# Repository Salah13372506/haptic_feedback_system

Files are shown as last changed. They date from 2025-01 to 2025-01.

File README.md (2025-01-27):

# Système de Retour Haptique avec Vision par Ordinateur

## Description du Projet

Projet réalisé dans le cadre du Master Systems for Rehabilitation (MSR) - Sorbonne Université.

Ce système d'assistance innovant a été conçu pour aider les personnes non-voyantes dans leur déplacement quotidien. Il combine la vision par ordinateur et le retour haptique pour détecter les obstacles et communiquer leur position à l'utilisateur via des vibrations. Développé initialement comme un système d'évitement d'obstacles, le projet a le potentiel d'évoluer vers une solution complète de navigation assistée.
Le système utilise une caméra de profondeur OAK-D pour détecter les obstacles et transmet l'information via des moteurs vibrants positionnés de manière ergonomique, permettant à l'utilisateur de percevoir intuitivement la direction des obstacles et de choisir un chemin sûr.
Ce projet s'inscrit dans une démarche d'innovation technologique au service de l'autonomie des personnes en situation de handicap visuel.






## Table des Matières

1. [Vue d'ensemble](#vue-densemble)
2. [Installation](#installation)
3. [Configuration de l'Espace de Travail](#configuration-de-lespace-de-travail)
4. [Nœuds ROS2](#nœuds-ros2)
5. [Partie Électronique](#partie-électronique)
6. [Partie Mécanique](#partie-mécanique)
7. [Documentation Utilisateur](#documentation-utilisateur)

## Vue d'ensemble

Ce projet implémente un système de détection d'obstacles et de retour haptique guidé par vision par ordinateur. Il utilise ROS2, une caméra de profondeur OAK-D, et des moteurs vibrants LRA (Linear Resonant Actuator) contrôlés par une carte Arduino MKR WiFi 1010.

## Installation

### Prérequis Système
- Ubuntu 22.04 LTS
- Python 3.10 ou supérieur
- Git
- VS Code avec PlatformIO

### ROS2 Humble
```bash
wget -c https://raw.githubusercontent.com/ros/rosdistro/master/ros.key && sudo apt-key add ros.key && sudo sh -c 'echo "deb [arch=amd64] http://packages.ros.org/ros2/ubuntu jammy main" > /etc/apt/sources.list.d/ros2.list' && sudo apt update && sudo apt install ros-humble-desktop-full
```

### Configuration Caméra OAK-D

1. Documentation officielle :
   - [Documentation Luxonis OAK-D](https://docs.luxonis.com/projects/api/en/latest/)
   - [Exemples DepthAI](https://github.com/luxonis/depthai-python/tree/main/examples)

2. Installation des dépendances :
   ```bash
   # Installation des dépendances système DepthAI
   sudo wget -qO- https://docs.luxonis.com/install_dependencies.sh | bash

   # Installation de la bibliothèque Python DepthAI
   python3 -m pip install depthai

   # Installation des dépendances ROS2
   sudo apt install ros-humble-depthai-ros
   ```

3. Test de l'installation :
   ```bash
   # Cloner les exemples
   git clone https://github.com/luxonis/depthai-python.git
   cd depthai-python/examples
   
   # Installer les dépendances Python
   python3 install_requirements.py
   
   # Tester la caméra
   python3 ColorCamera/rgb_preview.py
   ```

4. Vérification des règles udev :
   ```bash
   # Vérifier que la caméra est détectée
   lsusb | grep MyriadX
   
   # Si nécessaire, recharger les règles udev
   sudo udevadm control --reload-rules
   sudo udevadm trigger
   ```

### Configuration Arduino et PlatformIO (À lancer avant ROS2)

1. Installation de l'environnement de développement :
   ```bash
   # Installation de VS Code
   sudo apt update
   sudo apt install software-properties-common apt-transport-https wget
   wget -q https://packages.microsoft.com/keys/microsoft.asc -O- | sudo apt-key add -
   sudo add-apt-repository "deb [arch=amd64] https://packages.microsoft.com/repos/vscode stable main"
   sudo apt update
   sudo apt install code
   ```

2. Configuration de PlatformIO :
   - Ouvrir VS Code
   - Aller dans Extensions (Ctrl+Shift+X)
   - Rechercher "PlatformIO IDE"
   - Installer l'extension
   - Redémarrer VS Code

3. Structure du projet Arduino :
   ```
   haptic-arduino/
   ├── platformio.ini
   ├── src/
   │   └── main.cpp              # Code principal Arduino
   ├── lib/
   │   ├── Haptic_DRV2605/      # Bibliothèque des moteurs
   │   └── README.md
   └── include/
       └── README.md
   ```

4. Configuration détaillée dans `platformio.ini` :
   ```ini
   [env:mkrwifi1010]
   platform = atmelsam
   board = mkrwifi1010
   framework = arduino
   
   ; Configuration moniteur série
   monitor_speed = 115200
   monitor_flags = 
       --parity
       N
       --encoding
       UTF-8
   
   ; Dépendances externes
   lib_deps =
       arduino-libraries/WiFiNINA @ ^1.8.14
       bblanchon/ArduinoJson @ ^6.21.3
       Wire
       adafruit/Adafruit DRV2605 Library @ ^1.1.2
   
   ; Options de build
   build_flags =
       -D DEBUG_MODE
       -D WIFI_SSID=\"HapticArduino\"
       -D WIFI_PASS=\"haptic123\"
   
   ; Configuration mémoire
   board_build.f_cpu = 48000000L
   upload_speed = 115200
   ```

5. Compilation et téléversement :
   ```bash
   # Dans le dossier du projet Arduino
   pio run -t upload
   ```

6. Vérification du fonctionnement :
   ```bash
   # Ouvrir le moniteur série
   pio device monitor
   ```
   - Vérifier que l'Arduino crée bien le point d'accès WiFi
   - Confirmer l'initialisation des moteurs
   - Noter l'adresse IP (par défaut 192.168.4.1)

## Nœuds ROS2

### Objectifs des Nœuds

#### 1. Nœud Processeur de Profondeur (processor_node.py)
Ce nœud reçoit les données brutes de la caméra de profondeur et les traite pour identifier les obstacles.
Il normalise les données de profondeur et publie une image traitée où les obstacles proches sont plus sombres.

#### 2. Nœud de Projection 2D (2d.py)
Ce nœud transforme l'image de profondeur traitée en une projection 2D avec détection d'obstacles.
Il analyse la position des obstacles et détermine de quel côté l'utilisateur doit se diriger.

#### 3. Nœud de Publication Haptique (haptic_publisher.py)
Ce nœud gère l'activation des différents moteurs haptiques selon les commandes reçues.
Il maintient deux groupes de moteurs (gauche et droite) et coordonne leurs activations.

#### 4. Nœud Bridge WiFi (wifi_bridge.py)
Ce nœud établit la communication WiFi entre ROS2 et l'Arduino.
Il convertit les commandes ROS2 en messages JSON et les envoie à l'Arduino via UDP.

### Lancement des Nœuds

#### 1. Lancement de la Caméra
```bash
# Lance la caméra OAK-D et publie les données de profondeur
colcon build --symlink-install --packages-select depthai_bridge
colcon build --symlink-install --packages-select depthai_examples
source install/setup.bash
ros2 launch depthai_examples stereo_inertial_node.launch.py depth:=true
```

#### 2. Lancement des Nœuds de Traitement
```bash
# Compile et lance les nœuds de traitement de profondeur
colcon build --packages-select depth_processor
source install/setup.bash
ros2 run depth_processor processor_node
ros2 run depth_processor 2d_node
```

#### 3. Lancement des Nœuds Haptiques
```bash
# Compile et lance les nœuds de contrôle haptique
colcon build --packages-select haptic_control_interfaces haptic_control_pkg
source install/setup.bash
ros2 run haptic_control_pkg haptic_publisher
ros2 run haptic_control_pkg haptic_bridge
```

### Tests Rapides
```bash
# Active les moteurs gauches
ros2 topic pub /haptic_side haptic_control_interfaces/msg/SideCommand "{side: 2}"

# Active les moteurs droits
ros2 topic pub /haptic_side haptic_control_interfaces/msg/SideCommand "{side: 1}"
```

## Partie Électronique

### Liste du Matériel
- 1x Arduino MKR WiFi 1010
- 8x Moteurs LRA
- 1x Multiplexeur I2C TCA9548A
- 8x Drivers DRV2605
- 1x PCB personnalisée
- Composants:
  - Régulateur 3.3V
  - Condensateurs de découplage
  - Résistances pull-up
  - Connecteurs moteurs

### Carte PCB

La carte PCB a été conçue pour gérer 6 moteurs haptiques de type LRA. Elle intègre les composants suivants :

#### Composants Principaux
- 1x Arduino MKR WiFi 1010 (microcontrôleur principal)
- 6x Drivers DRV2605 (contrôle des moteurs LRA)
- 1x Multiplexeur I2C TCA9548A (gestion des multiples drivers)
- 6x Connecteurs JST femelles (connexion des moteurs)

#### Connexions
- Chaque moteur se connecte via un connecteur JST 2 pins pour :
  - VCC (alimentation)
  - GND (masse)

#### Communication
- Bus I2C distribué via le multiplexeur
- Le multiplexeur permet de gérer les 6 drivers avec une seule paire de lignes I2C




*Note : Tous les fichiers liés à la PCB sont disponibles dans le dossier `PCB_designing/` du projet*

### Configuration WiFi Arduino
- Mode: Point d'accès (AP)
- SSID: "HapticArduino"
- Password: "haptic123"
- IP Arduino: 192.168.4.1
- Port UDP: 8888
- Format: JSON

### Format des Messages JSON
```json
{
    "motor": 0-7,           // ID du moteur
    "waveform": 0-123,      // Pattern de vibration
    "activate": true/false,  // Activation/désactivation
    "intensity": 0.0-1.0    // Intensité de vibration
}
```

## Partie Mécanique

Le système comporte plusieurs pièces imprimées en 3D, chacune ayant une fonction spécifique :

### 1. Support Principal
- Pièce servant de base au système
- Conçue avec un système de clips pour maintenir la PCB
- Intègre un couvercle arrière pour protéger l'électronique
- Dimensions optimisées pour s'adapter à la PCB et au boîtier de la caméra



### 2. Support Moteur et Driver (Prototype)
- Prototype initial permettant d'accueillir :
  - Le moteur LRA
  - Son driver DRV2605
  - Les connexions nécessaires
- Bien que non utilisé dans la version finale, ce design reste pertinent pour des tests unitaires ou des prototypes




### 3. Support Moteur Simple
- Version optimisée pour maintenir uniquement le moteur LRA
- Design minimaliste pour réduire l'encombrement
- Système de fixation sécurisé pour le moteur
- Adapté pour l'intégration dans le système final




*Note : Tous les fichiers STL et les sources CAO sont disponibles dans le dossier `Solidworks/` du projet*

## Documentation Utilisateur

[Manuel Utilisateur PDF](lien_vers_manuel.pdf)

## Résolution des Problèmes

### Caméra non détectée
- Vérifier connexion USB
- Vérifier règles udev
- Redémarrer le service udev

### Erreurs WiFi
- Vérifier que l'Arduino crée bien le point d'accès
- Vérifier dans le moniteur série (115200 baud) le statut de la connexion
- Confirmer l'IP et le port dans le code

### Moteurs non réactifs
- Vérifier l'adresse du multiplexeur I2C (0x70)
- Vérifier les connexions des moteurs
- Utiliser le moniteur série pour voir les messages d'initialisation

## Contact
Pour toute question sur ce projet, contactez les auteurs via LinkedIn.

## Auteurs et Remerciements

### Auteurs
- Amal BECHEKER
- Salah Eddine HAMIZI
- Vincent FONROUGE

### Remerciements
Nous tenons à remercier particulièrement :
- M. Fabien VÉRITÉ pour la gestion et la coordination du Master MSR
- L'équipe pédagogique de Sorbonne Université

Projet réalisé dans le cadre du Master MSR - Sorbonne Université, 2024.

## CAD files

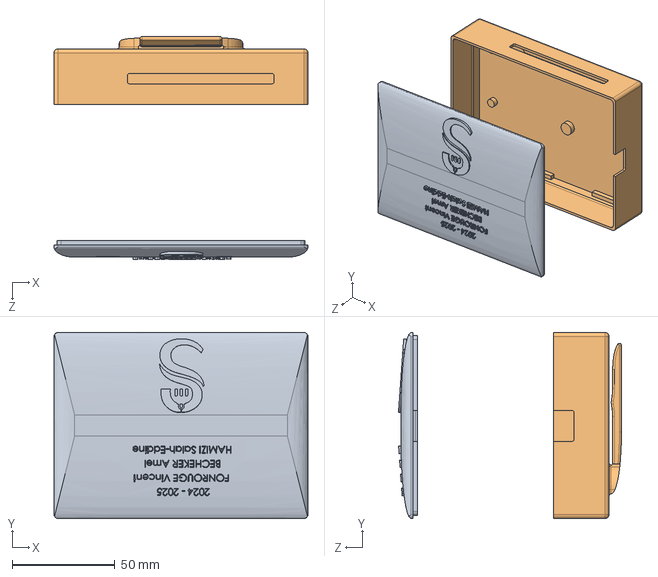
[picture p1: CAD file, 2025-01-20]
Solidworks/Assemblage_boitier.SLDASM
123.4 x 90.4 x 108.4 mm
case_bas
couvercle

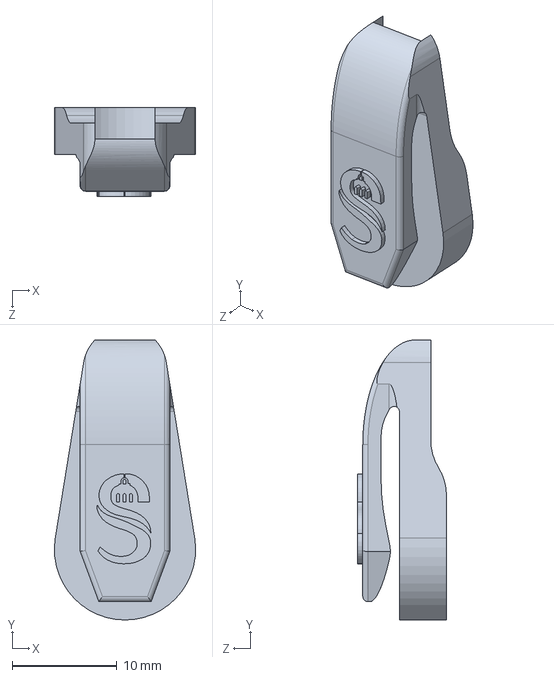
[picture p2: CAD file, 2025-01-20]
Solidworks/support_LRA.SLDPRT
13.5 x 26.8 x 8.50 mm

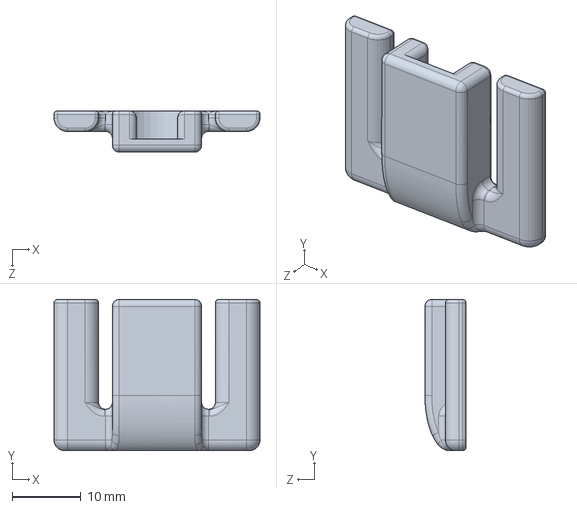
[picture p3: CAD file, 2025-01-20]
Solidworks/support_LRA_court.SLDPRT
30.0 x 22.0 x 6.00 mm

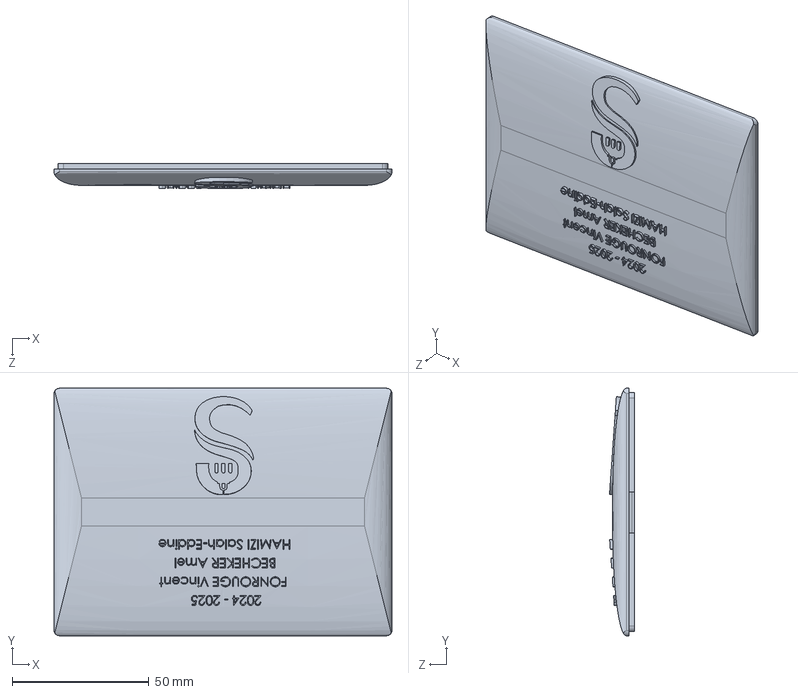
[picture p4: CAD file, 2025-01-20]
Solidworks/couvercle.SLDPRT
123.4 x 90.4 x 9.15 mm

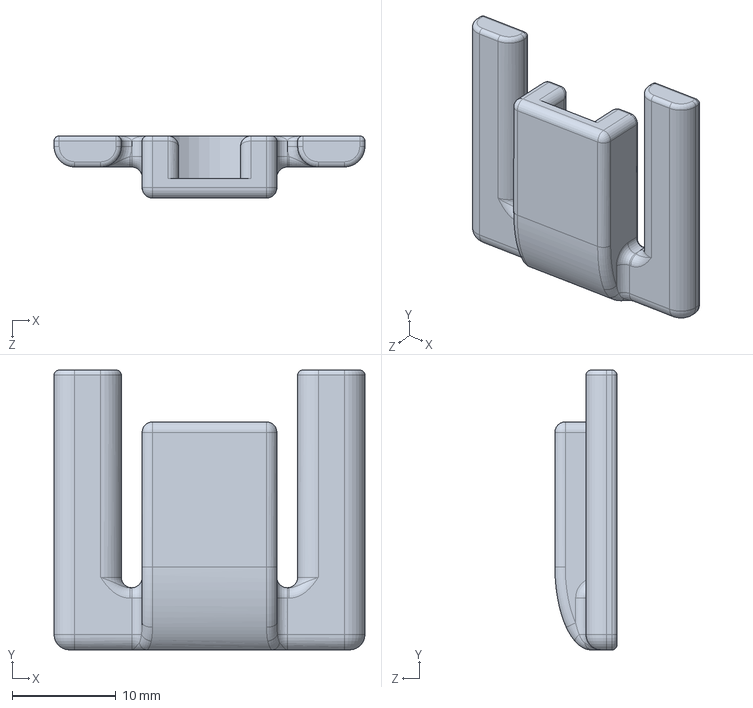
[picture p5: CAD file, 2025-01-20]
Solidworks/support_LRA_long.SLDPRT
30.0 x 27.0 x 6.00 mm

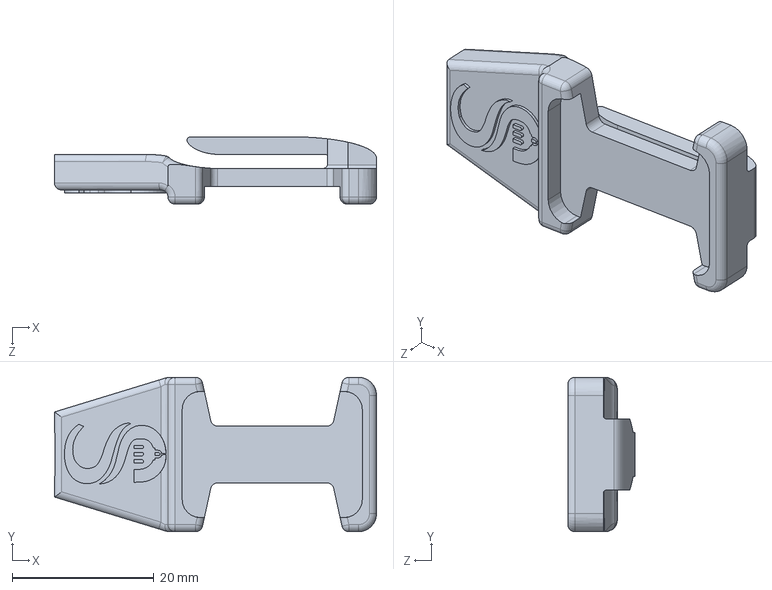
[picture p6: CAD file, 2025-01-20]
Solidworks/support_driver_v2.SLDPRT
45.4 x 21.8 x 9.50 mm

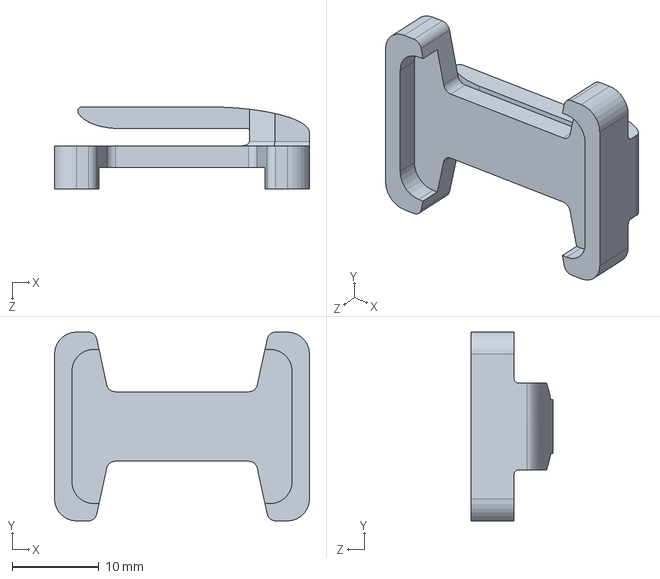
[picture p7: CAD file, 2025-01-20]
Solidworks/support_driver.SLDPRT
29.4 x 21.8 x 9.50 mm

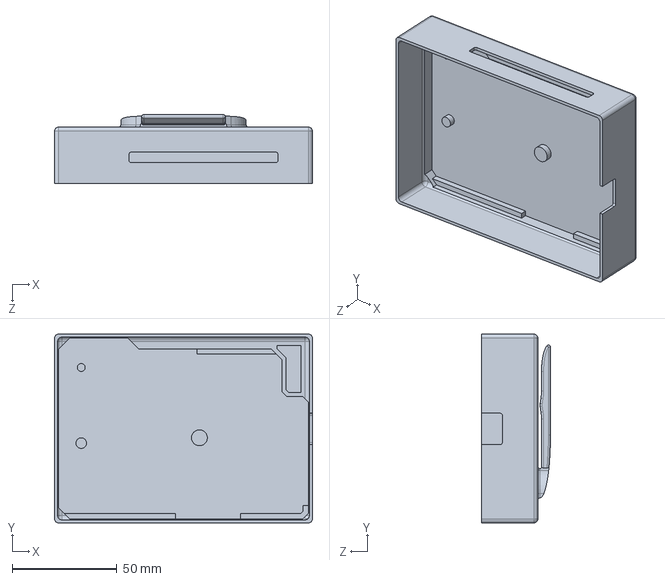
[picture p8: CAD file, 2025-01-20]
Solidworks/case_bas.SLDPRT
123.4 x 90.4 x 33.0 mm

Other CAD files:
Solidworks/pcb_designing.SLDPRT
Solidworks/case_bas.STL
Solidworks/couvercle.STL
Solidworks/support_LRA.STL
Solidworks/support_LRA_court.STL
Solidworks/support_LRA_long.STL
Solidworks/support_driver.STL
Solidworks/support_driver_v2.STL

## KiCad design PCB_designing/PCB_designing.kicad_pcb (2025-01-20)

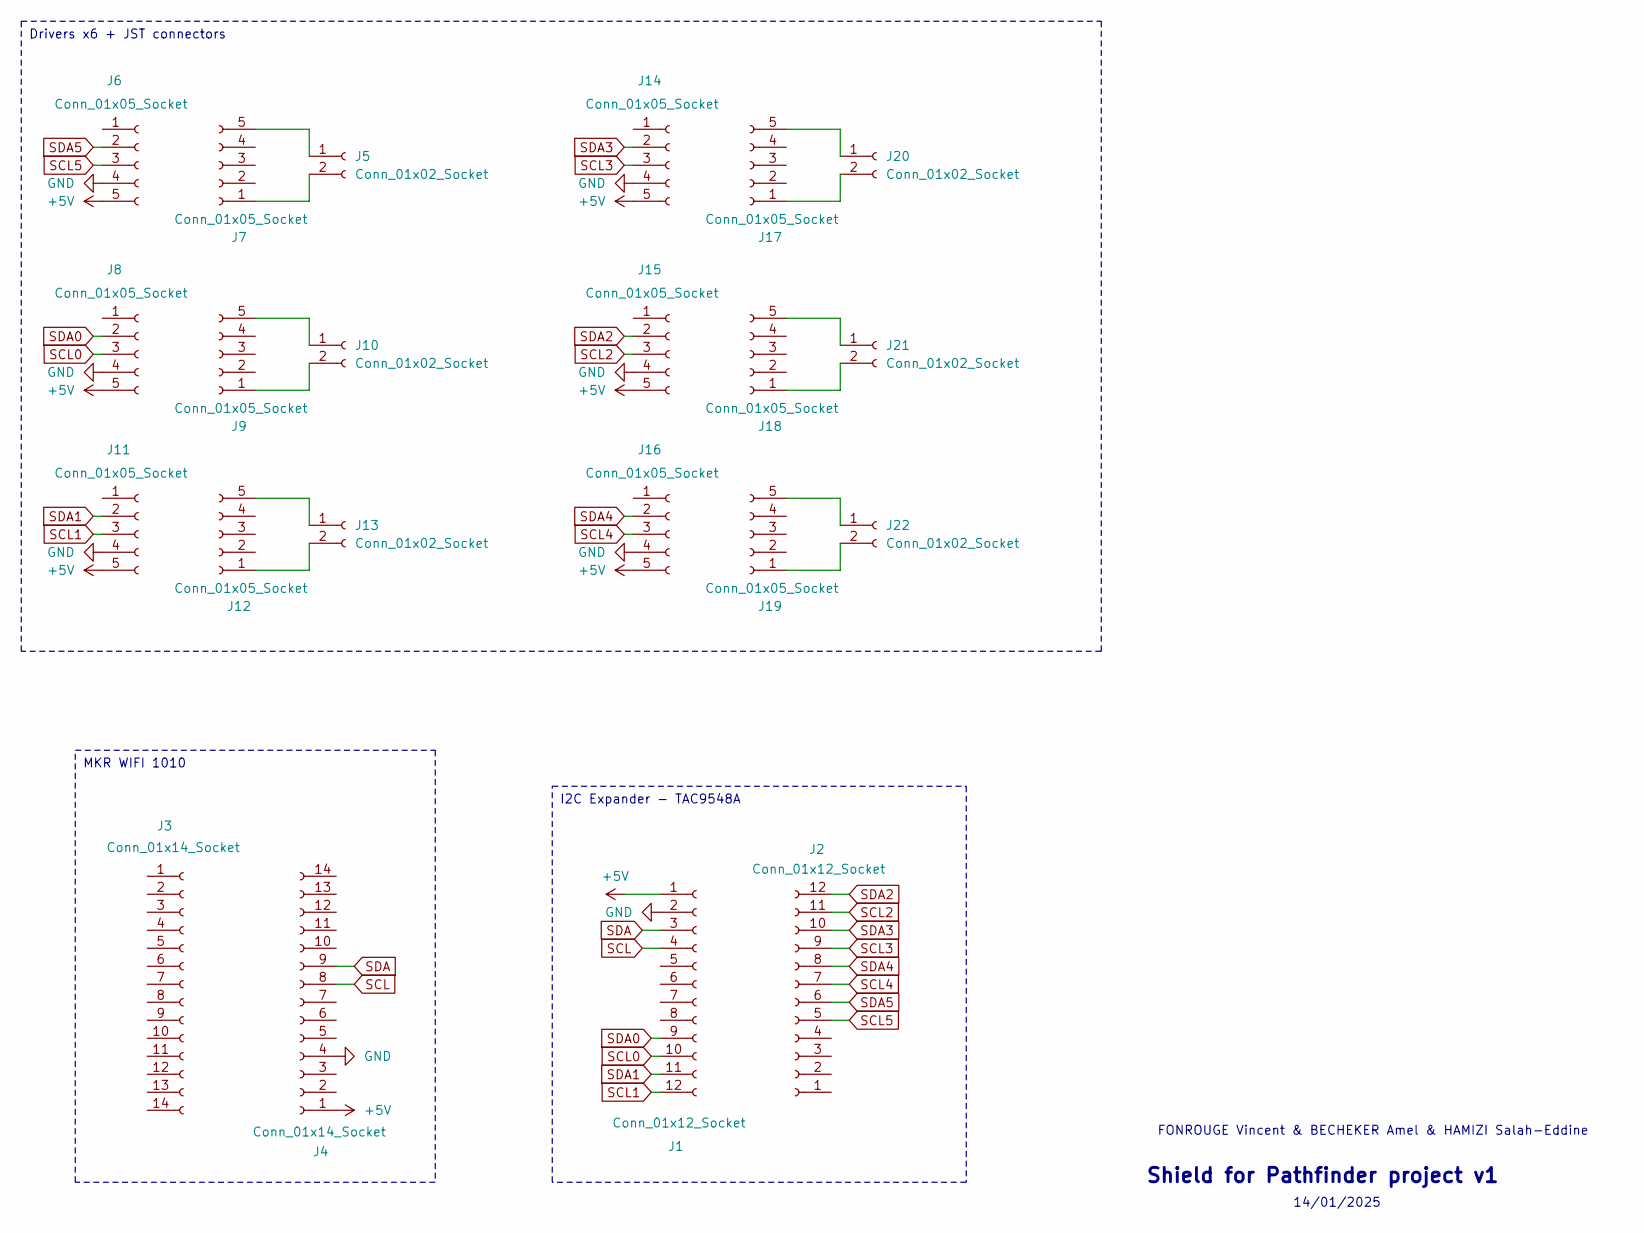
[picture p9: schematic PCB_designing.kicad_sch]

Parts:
J1, J2: Conn_01x12_Socket; PinSocket_1x12_P2.54mm_Vertical
J3, J4: Conn_01x14_Socket; PinSocket_1x14_P2.54mm_Vertical
J5, J10, J13, J20, J21, J22: Conn_01x02_Socket; JST_EH_S2B-EH_1x02_P2.50mm_Horizontal
J6, J7, J8, J9, J11, J12, J14, J15, J16, J17, J18, J19: Conn_01x05_Socket; PinSocket_1x05_P2.54mm_Vertical

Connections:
+5V: J1.1, J4.1, J6.5, J8.5, J11.5, J14.5, J15.5, J16.5
GND: J1.2, J4.4, J6.4, J8.4, J11.4, J14.4, J15.4, J16.4
unnamed: J5.1, J7.5
unnamed: J5.2, J7.1
unnamed: J9.5, J10.1
unnamed: J9.1, J10.2
unnamed: J12.1, J13.2
unnamed: J12.5, J13.1
unnamed: J17.1, J20.2
unnamed: J17.5, J20.1
unnamed: J18.1, J21.2
unnamed: J18.5, J21.1
unnamed: J19.1, J22.2
unnamed: J19.5, J22.1
SCL: J1.4, J4.8
SCL0: J1.10, J8.3
SCL1: J1.12, J11.3
SCL2: J2.11, J15.3
SCL3: J2.9, J14.3
SCL4: J2.7, J16.3
SCL5: J2.5, J6.3
SDA: J1.3, J4.9
SDA0: J1.9, J8.2
SDA1: J1.11, J11.2
SDA2: J2.12, J15.2
SDA3: J2.10, J14.2
SDA4: J2.8, J16.2
SDA5: J2.6, J6.2

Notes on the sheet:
Drivers x6 + JST connectors
MKR WIFI 1010
I2C Expander - TAC9548A
FONROUGE Vincent & BECHEKER Amel & HAMIZI Salah-Eddine
Shield for Pathfinder project v1
14/01/2025

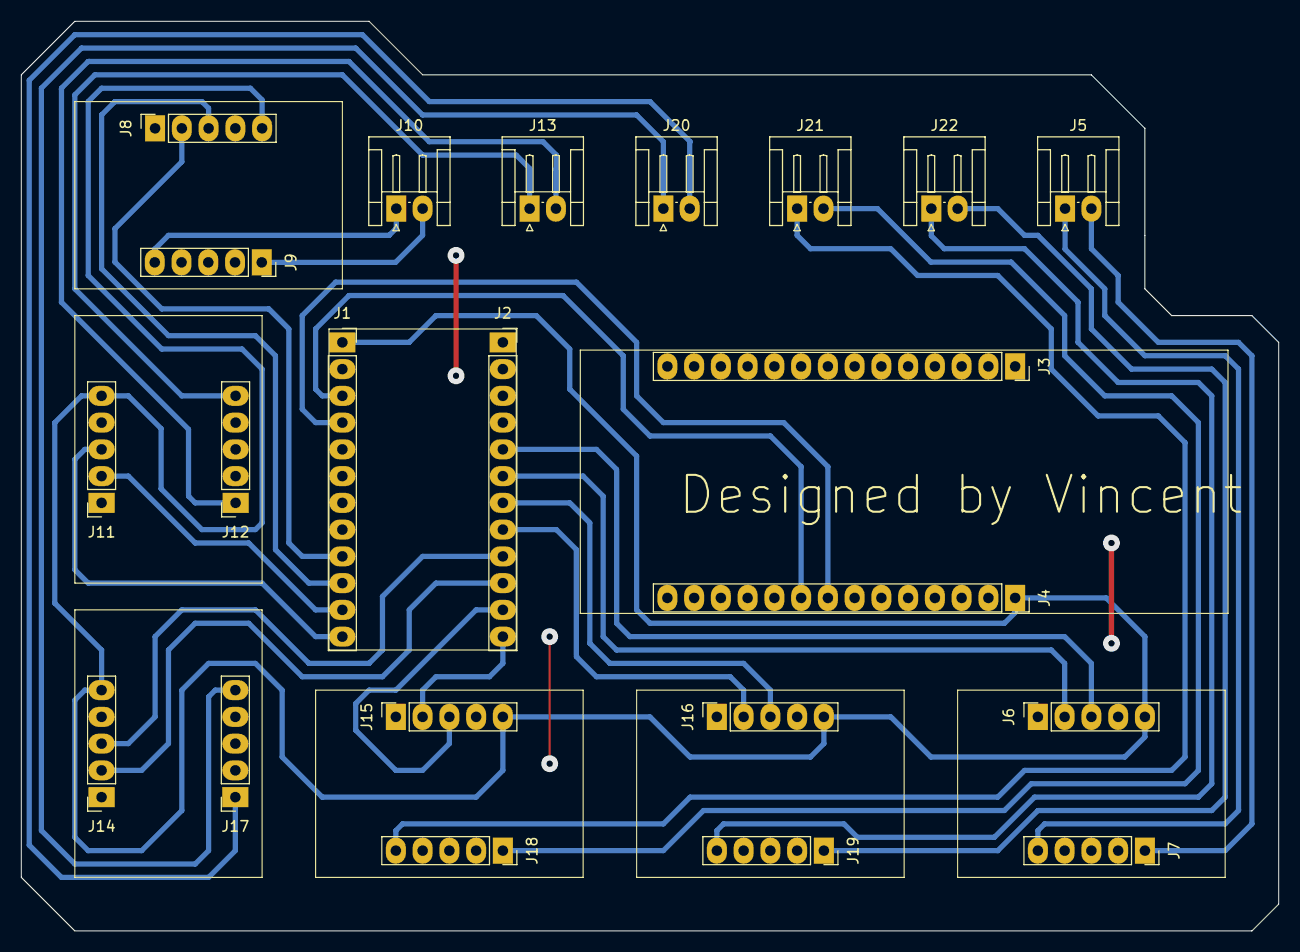
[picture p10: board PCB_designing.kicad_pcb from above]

Board: 2 copper layers, 119.4 x 86.4 mm, 22 parts (0 on the bottom side), 28 nets.

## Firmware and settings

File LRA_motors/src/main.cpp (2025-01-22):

#include <WiFiNINA.h>
#include <ArduinoJson.h>
#include <Wire.h>
#include "Haptic_DRV2605.h"

// Configuration WiFi
const char* ap_ssid = "HapticArduino";     // Nom du réseau que va créer l'Arduino
const char* ap_password = "haptic123";      // Mot de passe (minimum 8 caractères)
const int localPort = 8888;


// Configuration IP fixe
IPAddress local_ip(192, 168, 4, 1);
IPAddress gateway(192, 168, 4, 1);
IPAddress subnet(255, 255, 255, 0);

// Configuration TCA9548A
#define TCA9548A_ADDRESS 0x70

// Tableau des moteurs
Haptic_DRV2605 haptic[6];

// Buffer pour les données UDP
WiFiUDP udp;
char packetBuffer[256];

void tcaSelect(uint8_t channel) {
  if (channel > 5) return;
  Wire.beginTransmission(TCA9548A_ADDRESS);
  Wire.write(1 << channel);
  Wire.endTransmission();
}

void setupWiFi() {
    Serial.println("Configuration du point d'accès WiFi...");
    
    // Créer le réseau WiFi
    if (WiFi.beginAP(ap_ssid, ap_password) != WL_AP_LISTENING) {
        Serial.println("Erreur création point d'accès !");
        while (true); // Arrêt si échec de création
    }

    // Laisser le temps au point d'accès de démarrer
    delay(2000);

    // Vérifier le statut
    while (WiFi.status() != WL_AP_LISTENING) {
        Serial.println("En attente du démarrage du point d'accès...");
        delay(500);
    }
    
    // Afficher les informations de connexion
    Serial.println("Point d'accès créé avec succès !");
    Serial.println("Configuration réseau :");
    Serial.print("    SSID : ");
    Serial.println(ap_ssid);
    Serial.print("    IP : ");
    Serial.println(WiFi.localIP());
    Serial.print("    Port : ");
    Serial.println(localPort);
    
    // Démarrer le serveur UDP sur le port spécifié
    udp.begin(localPort);
    Serial.println("Serveur UDP démarré");
    
    // Afficher un message pour indiquer que l'Arduino est prêt
    Serial.println("Arduino prêt à recevoir des commandes UDP");
}


void setupHapticMotors() {
  Wire.begin();
  
  // Initialisation de tous les moteurs
  for (uint8_t channel = 0; channel < 6; channel++) {
    tcaSelect(channel);
    
    if (haptic[channel].begin() == HAPTIC_SUCCESS) {
      Serial.print("Moteur initialisé sur le canal ");
      Serial.println(channel);
      
      haptic[channel].setActuatorType(LRA);
      haptic[channel].setMode(REGISTER_MODE);
    } else {
      Serial.print("Erreur d'initialisation moteur canal ");
      Serial.println(channel);
    }
  }
}

void handleHapticCommand(int motor_id, int waveform, bool activate, float intensity) {
  if (motor_id < 0 || motor_id > 5) return;
  
  tcaSelect(motor_id);
  
  if (activate) {
    // Convertir l'intensité (0.0-1.0) en valeur compatible DRV2605 
    uint8_t strength = intensity * 127;
    haptic[motor_id].setRealtimeValue(strength);
    
    haptic[motor_id].setWaveform(0, waveform);
    haptic[motor_id].setWaveform(1, 0);  // Stop
    haptic[motor_id].go();  // Démarrer la séquence
  } else {
    haptic[motor_id].stop();
  }
}

void setup() {
  Serial.begin(115200);
  
  setupWiFi();
  setupHapticMotors();
}

void loop() {
    // Vérifier si des données UDP sont disponibles
    int packetSize = udp.parsePacket();
    if (packetSize) {
        Serial.print("Paquet UDP reçu, taille: ");
        Serial.println(packetSize);
        
        // Lire le paquet
        int len = udp.read(packetBuffer, 255);
        if (len > 0) {
            packetBuffer[len] = 0;  // Null-terminate string
            Serial.print("Message reçu: ");
            Serial.println(packetBuffer);
            
            // Parse le JSON
            StaticJsonDocument<200> doc;
            DeserializationError error = deserializeJson(doc, packetBuffer);
            
            if (!error) {
                // Extraire les valeurs
                int motor = doc["motor"];
                int waveform = doc["waveform"];
                bool activate = doc["activate"];
                float intensity = doc["intensity"];
                
                Serial.println("Commande décodée:");
                Serial.print("  Motor: "); Serial.println(motor);
                Serial.print("  Waveform: "); Serial.println(waveform);
                Serial.print("  Activate: "); Serial.println(activate);
                Serial.print("  Intensity: "); Serial.println(intensity);
                
                // Appliquer la commande
                handleHapticCommand(motor, waveform, activate, intensity);
            } else {
                Serial.print("Erreur parsing JSON: ");
                Serial.println(error.c_str());
            }
        }
    }
}

// ls -l /dev/ttyACM*
// sudo dmesg | grep tty
// sudo chmod 666 /dev/ttyACM0

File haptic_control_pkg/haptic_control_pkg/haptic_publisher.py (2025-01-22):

#!/usr/bin/env python3
#!/usr/bin/env python3
import rclpy
from rclpy.node import Node
from haptic_control_interfaces.msg import SideCommand
try:
    # Changez cette ligne pour utiliser le nouveau package d'interfaces
    from haptic_control_interfaces.msg import HapticCommand
except ImportError as e:
    print(f"Error importing HapticCommand message: {e}")
    print("Make sure haptic_control_interfaces is properly built and sourced")
    raise
class HapticPublisher(Node):
    def __init__(self):
        super().__init__('haptic_publisher')
        
        # Créer le publisher
        self.publisher = self.create_publisher(
            HapticCommand,
            'haptic_commands',
            10)
            
        # Paramètres
        self.declare_parameter('default_intensity', 0.8)
        self.default_intensity = self.get_parameter('default_intensity').value
        
        # Ajout des constantes pour les groupes de moteurs
        self.RIGHT_MOTORS = [0, 1, 3]
        self.LEFT_MOTORS = [2,4,5]

        # Ajout du subscriber pour les commandes de côté
        self.side_subscription = self.create_subscription(
            SideCommand,
            'haptic_side',
            self.side_callback,
            10)
        
    def send_haptic_command(self, motor_id: int, waveform: int, activate: bool, intensity: float = None):
        """
        Envoie une commande à un moteur spécifique.
        
        Args:
            motor_id (int): ID du moteur (0-7)
            waveform (int): Pattern de vibration (0-123)
            activate (bool): Activer/désactiver le moteur
            intensity (float, optional): Intensité de la vibration (0.0-1.0)
        """
        msg = HapticCommand()
        msg.motor_id = motor_id
        msg.waveform = waveform
        msg.activate = activate
        msg.intensity = intensity if intensity is not None else self.default_intensity
        
        self.publisher.publish(msg)
        self.get_logger().info(
            f'Envoi commande: Motor {motor_id}, Waveform {waveform}, '
            f'Activate {activate}, Intensity {msg.intensity}'
        )

    def activate_motor(self, motor_id: int, waveform: int = 56, intensity: float = None):
        """Active un moteur avec les paramètres spécifiés."""
        self.send_haptic_command(motor_id, waveform, True, intensity)

    def deactivate_motor(self, motor_id: int):
        """Désactive un moteur spécifique."""
        self.send_haptic_command(motor_id, 0, False, 0.0)

    def activate_sequence(self, motor_sequence: list, delay: float = 0.1):
        """
        Active une séquence de moteurs.
        
        Args:
            motor_sequence (list): Liste des IDs de moteurs à activer en séquence
            delay (float): Délai entre chaque activation (en secondes)
        """
        def trigger_next(idx):
            if idx >= len(motor_sequence):
                return
            
            motor_id = motor_sequence[idx]
            self.activate_motor(motor_id)
            
            if idx < len(motor_sequence) - 1:
                self.create_timer(delay, lambda: trigger_next(idx + 1))
        
        trigger_next(0)

    def activate_motor_group(self, motors, waveform=56, intensity=None):
        """Active un groupe de moteurs avec les mêmes paramètres"""
        for motor_id in motors:
            self.activate_motor(motor_id, waveform, intensity)

    def deactivate_motor_group(self, motors):
        """Désactive un groupe de moteurs"""
        for motor_id in motors:
            self.deactivate_motor(motor_id)

    def side_callback(self, msg):
        """Callback pour les commandes de côté"""
        # Désactiver tous les moteurs d'abord
        self.deactivate_motor_group(self.RIGHT_MOTORS + self.LEFT_MOTORS)

    #Activer le groupe approprié
        if msg.side == SideCommand.RIGHT:
            self.activate_motor_group(self.RIGHT_MOTORS)
            self.get_logger().info('Activating RIGHT motors')
        else:
            self.activate_motor_group(self.LEFT_MOTORS)
            self.get_logger().info('Activating LEFT motors')    

def main(args=None):
    rclpy.init(args=args)
    haptic_publisher = HapticPublisher()
    
    try:
        rclpy.spin(haptic_publisher)
    except KeyboardInterrupt:
        pass
    finally:
        haptic_publisher.destroy_node()
        rclpy.shutdown()

if __name__ == '__main__':
    main()
